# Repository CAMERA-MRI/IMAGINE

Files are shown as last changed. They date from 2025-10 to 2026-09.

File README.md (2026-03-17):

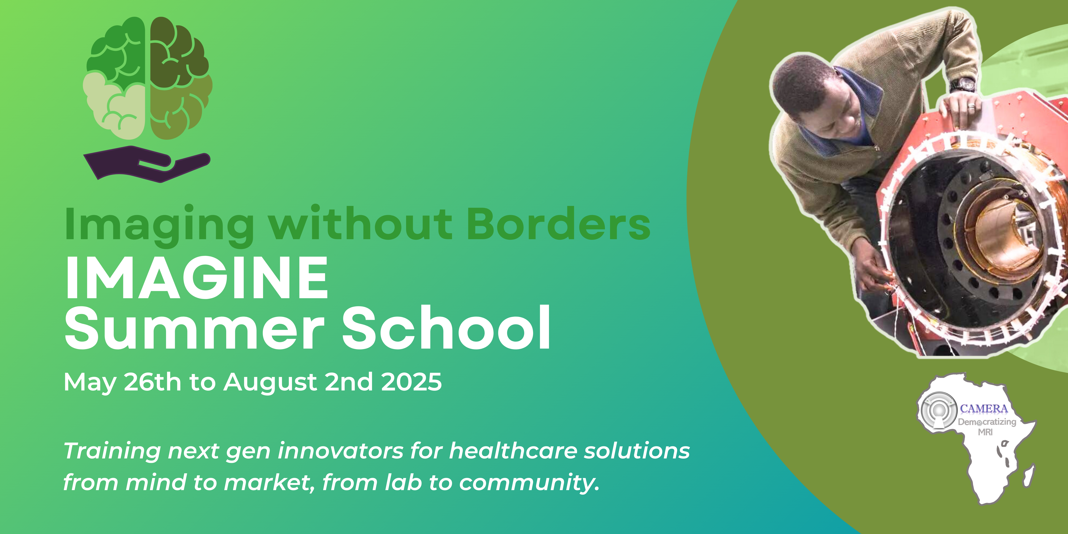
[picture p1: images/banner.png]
Banner.
<br/><br/>

# IMAGINE: Imaging Without Borders: Building a low-cost open-source low-field preclinical MR scanner. 

Imaging without Borders (IMAGINE) summer school is a hybrid training initiative of the Consortium for Advancement of MRI Education and Research in Africa (CAMERA). The summer school is designed to provide skills training to biomedical engineers and MR imaging personnel working in MRI hardware and scanner maintenance in Low- and Middle-income countries (LMICs) in Africa, Latin America, and Southeast Asia or clinicians and researchers interested in low-field and accessible imaging. IMAGINE implements RAD-AID’s Teach-Try-Use strategy, applied in CAMERA’s SPARK AI training program, to rapidly provide MR hardware and engineering competencies in resource-limited settings. In keeping with CAMERA’s training model, IMAGINE will use a combination of case-based and hands-on learning approaches to train a team of engineers, physicists, clinicians, and researchers who will work together as a network to grow their skills and collectively train others. IMAGINE is focused on training next-generation imaging innovators on how to use design thinking strategies and user-centered problem-solving skills to create low-cost open-source tools that will sustainably democratize diagnostic imaging and make it readily accessible to all. 

### Field Mapping Robot
Hardware and firmware developed for the IMAGINE field mapping robot are available here:  
➡️ [https://github.com/SipanHovsep/Field_mapper_robot](https://github.com/SipanHovsep/Field_mapper_robot)

### Halbach Design Genetic Algorithm
Code to the Magnet design Genetic Algorithm developed and used during IMAGINE can be accessed here: \
➡️ [https://github.com/tmachtelinckx/halbacharray-GA](https://github.com/tmachtelinckx/halbacharray-GA)

The files needed for the magnet configuration used for the scanner build in the IMAGINE Summer School are in the Halbach Array folder. These files are meant to be opened in Autodesk Inventor or Fusion360. There are also .stp files for the individual rings so you can see how it would print.

### RF Coil 
.stp files to print the RF Coil holder and description of all the necessary parameters are provided in the RF Coil folder.

### TR Switch
The switch used is the passive switch from the [Open Source Imaging Initiative](https://gitlab.com/osii/rf-system/tr-switches/passive-tr-switch). 

### The Control System used is MaRCoS controlled from the MARGE GUI
➡️ [MaRCoS MRI](https://github.com/marcos-mri) \
➡️ [MaRGE: A graphical environment for MaRCoS](https://github.com/josalggui/MaRGE)

## Citations
[1] Anazodo, Udunna C et al. “A framework for advancing sustainable magnetic resonance imaging access in Africa.” NMR in biomedicine vol. 36,3 (2023): e4846. doi:10.1002/nbm.4846 \
[2] Murali, Sanjana et al. “Bringing MRI to low- and middle-income countries: Directions, challenges and potential solutions.” NMR in biomedicine vol. 37,7 (2024): e4992. doi:10.1002/nbm.4992 \
[3] Negnevitsky, V., Vives-gilabert, Y., Algarín, J. M., Craven-Brightman, L., Pellicer-guridi, R., O'Reilly, T., Stockmann, J. P., Webb, A., Alonso, J., & Menküc, B. (2023). MaRCoS, an open-source electronic control system for low-field MRI. Journal of Magnetic Resonance, 350, 107424. https://doi.org/10.1016/j.jmr.2023.107424  \
[4] Algarín, J. M., Guallart-Naval, T., Borreguero, J., Galve, F., & Alonso, J. (2024). MaRGE: A graphical environment for MaRCoS. Journal of Magnetic Resonance, 361, 107662. https://doi.org/10.1016/j.jmr.2024.107662

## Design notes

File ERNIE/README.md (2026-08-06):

# 🧰 ERNIE 

 ## Overview

<p style="text-align: justify;">
The <b>CAMERA-IMAGINE-MRI Education (ERNIE) toolkit</b> was designed to facilitate immersive hands-on collaborative learning of open source (OS) low-field (LF) MRI engineering. ERNIE is a frugal educational toolkit for on-site construction of a 50 mT OS-LF ‘mice-like’ brain MRI scanner that can be readily reproduced in any setting using common assembly tools and without prior MRI engineering experience. The toolkit was designed as a reusable teaching resource consisting of:</p>

   1. A [30-minute lecture on OS-LF MR engineering concepts](https://github.com/CAMERA-MRI/IMAGINE/blob/main/ERNIE/Training%20sessions/Training%20material/Building%20your%20own%20Low%20field%20MRI_Dr%20Johnes_(%20MRI%20Uganda%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).

2. An [animation](https://github.com/CAMERA-MRI/IMAGINE/tree/main/ERNIE/Build%20your%20own%20Design/Magnet/Instructions/Animation) providing a step-by-step guide for scanner assembly, including the [magnet assembly guide](https://github.com/CAMERA-MRI/IMAGINE/blob/main/ERNIE/Build%20your%20own%20Design/Magnet/Instructions/How%20to%20Assemble%20the%20Magnet.pdf), [robot assembly guide and field mapping (quality assurance)](https://github.com/SipanHovsep/Field_mapper_robot).

3. A [bill of materials](https://github.com/CAMERA-MRI/IMAGINE/tree/main/ERNIE/Build%20your%20own%20Design) and [3D printing instructions for the magnet](https://github.com/CAMERA-MRI/IMAGINE/blob/main/ERNIE/Build%20your%20own%20Design/Magnet/Instructions/ERNIE%203D%20printing%20instructions.pdf) and robotic field mapping parts.

4. [Tools for onsite assembly](https://github.com/CAMERA-MRI/IMAGINE/tree/main/ERNIE/Build%20your%20own%20Design).

5. Instructions and software to build the magnet and map its field homogeneity.

6. The [magnet](https://github.com/CAMERA-MRI/IMAGINE/tree/main/ERNIE/Build%20your%20own%20Design/Magnet): a 7-ring, 80 mm (inner bore diameter) Halbach array producing ~50 mT, made from 98 neodymium (N48) magnets.
### ERNIE Toolkit  🧲 for Onsite Assembly and Magnetic Field Mapping with Portable Storage System
      
<p align="center">
toolkit
</p>
<p style="text-align: justify;">
 
### 💡 Objective
To provide a low-cost/open-source/hands-on educational toolkit for practical learning of Halbach-based MRI scanner assembly and field mapping. 
   
<p align="center"> 
   Objective 
</p>
   
### 🎯 Motivation
Practical experience in assembling low-field MRI scanners is rarely available to MRI researchers, which limits their understanding of MR physics and hardware design principles.   

<p align="center">
 New Motivation </p>
 
### ♻️ Reproducibility
<p style="text-align: justify;">
Two kits were designed as <b>ERNIE 1 & ERNIE 2 </b> as the <b>same kit </b> built at <b>2 different sites</b>. ERNIE 1 was first assembled at the 2025 ESMRMB pre-congress workshop and then re-assembled at the 2026 ISMRM conference in Cape Town, South Africa. ERNIE 2 on the other hand was first assembled at the Montreal Neurological Institute (MNI - The Neuro) and then re-assembled multiple times at the Montreal General Hospital, Polytechnique Montreal, The Douglas Health Hospital and 2026 ISMRM.
</p>
   
### ⭐ Impact
This toolkit was used to train participants at the ESMRMB 2025 Conference, The Montreal Neurological Institute, The Douglas, Polytech Montreal, Montreal General Hospital and ISMRM 2026 Conference. 

| **Metric** | **ESMRMB** | **Montreal Neurological Institute** | **Polytechnique Montréal** | **The Douglas** | **Montreal General Hospital** | **ISMRM** |
|:---|---:|---:|---:|---:|---:|---:|
| 🎓 **Training session** | ESMRMB | MNI | Polytechnique | Douglas | MGH | ISMRM |
| ⏱️ **Duration** | 7 h | 5 h | 3 h | 3 h | 3 h | 1.5 h |
| 👥 **Participants** | 59 | 26 | 13 | 20 | 18 | 86 |

 ### 🌍👥 Participants at different sites 

<p align="center">
   
   poly and neuro
</p>
<p align="center">
   ismrm git
   mgh and douglas pic for git
 </p>

   </p>
</p>

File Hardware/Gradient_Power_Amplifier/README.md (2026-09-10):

# Gradient Power Amplifier

The IMAGINE MRI scanner uses the open-source
[GPA-FHDO gradient power amplifier](https://github.com/menkueclab/GPA-FHDO)
to drive the X, Y, and Z gradient coils.

The GPA-FHDO is a four-channel gradient power amplifier designed for
low-field MRI applications. In the IMAGINE scanner, three channels are
used to drive the three gradient axes.

> **Note:** The GPA used in the IMAGINE scanner is based on the original
> GPA-FHDO design. Some components and implementation details were added
> or modified for our scanner configuration.

## Bill of Materials

The complete bill of materials (BOM) for the IMAGINE gradient power
amplifier is available here:

[Download the IMAGINE GPA BOM](./IMAGINE_GPA_BOM.xlsx)

The BOM includes the components used in our implementation, including
components that differ from or were added to the original GPA-FHDO design.

## Original GPA-FHDO Project

Original design and documentation:

https://github.com/menkueclab/GPA-FHDO

https://gpa-fhdo.readthedocs.io/en/latest/

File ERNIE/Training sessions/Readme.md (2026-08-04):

# 👥 Training Sessions
## Overview

<p style="text-align: justify;">
This section includes the educational sessions and training material related information.
Below are some of survey responses from the participants. We also includes a figure showing the robot and scanner setup during field mapping, field map results and a plot from one of the workshops (Montreal General Hospital Workshop). 
<p align= "center">

## 🧲Magnet, 🤖Robot setup and 📈 Magnetic Field Map Result.
 
<p align= "center">
  field map example
</p>

</p>

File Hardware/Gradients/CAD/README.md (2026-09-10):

# Gradient Coil CAD Files
This folder contains CAD and STL files for the X, Y, and Z gradient coil formers used in the low-field IMAGINE Halbach array MRI scanner.
STL files are provided for 3D printing.

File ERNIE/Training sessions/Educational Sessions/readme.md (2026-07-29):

# 🧑‍🏫 Educational Sessions
## Overview
<p style="text-align: justify;">
We conducted educational sessions to test the reproducibility of the ERNIE toolkit. This section includes educational apprach used and agendas used during the training sessions.

  <p align="center"> educational approach
</p>

## ESMRMB workshop Agenda
<p align="center"> esmrmb agenda</p>

## Montreal General Hospital (MGH) workshop Agenda 

<p align="center"> Mgh build session agenda 
</p>
</p>

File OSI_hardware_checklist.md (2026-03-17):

# OSI² CAB Review

## Review details

```
Project name: 
Project version: 
Project files: 

Review ID: 1.1/xx
Reviewer: 
Date: 
Approved: Yes / No
Total Points Hardware: XX / 17
```

---

## Note to Reviewers

- Please go through the checklist and provide detailed feedback that might be helpful to the project representative to justify a review score e.g. if you don't check a box, please explain what exactly is missing if appropriate.
- Each project is reviewed by at least 2 reviewers.
- If a project is being resubmitted, this is indicated with reference to the previous review report and the changes that have been made/points that were addressed.
- Mandatory requirements for projects to be published on [opensourceimaging.org](https://opensourceimaging.org/projects) are marked **in bold**.
- Open-source licenses for the project are checked beforehand by the `CAB Admin` or `CAB Editor`
- If a question is not applicable to the project, please check the box and write a short comment.
- If the hardware project contains software, please perform also the software review
- For questions and guidelines see also our CAB instructions [here](https://gitlab.com/osiiev/cab/-/blob/main/README.md).

---

## Scores for Hardware

### Readme

1. [x] **Is a README file (or equivalent) available with a project description?** (1)
2. [ ] Have the design considerations been explained? (1)

### Bill of Materials

1. [x] **Is a Bill of Materials (BoM) provided to reproduce the design?** (1)
2. [ ] Is the Bill of Materials complete/complies with our [best practices](https://gitlab.com/osiiev/cab/-/blob/main/guidelines/bill-of-materials.md)? (1)

### Source Files

1. [ ] **Are all files needed to reproduce the project according to the project description available in their native file format?** (1)

### Status of Freedom

1. [x] Are all source files editable with open-source software (e.g. FreeCAD, KiCAD)? (1)

### Production Files

1. [x] **Are all files needed to reproduce the project according to the project description available in a generally accessible export file format (e.g. STP, STL, GRB)?** (1)
2. [ ] Is the manufacturing environment (e.g. machine parameters) well defined or sufficiently explained to reproduce the production as intended? (1)
    > For instance, this is already given for a PCB, when complete Gerber files are provided. Then please grant this point.

### Assembly

1. [x] **Is the assembly of the project sufficiently explained, allowing for the complete replication of the project, e.g. by an assembly guide?** (1)
    > For some projects the assembly is clearly self-explanatory or not even needed, e.g. for one-piece 3D prints. Then please grant this point. 

### Development Tracking

1. [x] **Is a versioning scheme implemented (e.g. git repository)** (1)
2. [ ] Is an issue tracking implemented publicly? (1) 
3. [ ] Does the project have a communication space for questions, ideas, exchange with the developers or a user community? (1)

### Testing

1. [ ] Are testing routines available to evaluate the expected performance of the final design? (1)
2. [ ] Are testing routines complete (e.g. available for all subcomponents/subprocesses of the project build)? (1)

### Use

1. [ ] Is a user manual available? (1)
    > In case the intended use is clearly self-explanatory, so a manual is not needed. Then please grant this point.
2. [ ] Is a risk assessment or a safety notice available? (1)
3. [ ] Is information available (e.g. contact persons) if the project has been independently successfully replicated? (1)

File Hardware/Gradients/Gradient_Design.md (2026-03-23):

### How to build your own MRI Gradients
- CAD Design
- Gradient Optimization 
# How to build your own MRI Gradients
## CAD Design
The steps for the CAD design and 3D printing of the gradient coils using Autodesk AutoCAD

**Phase 1: Coordinate Import and Path Creation**

1. Data Preparation: Copy the x, y, and z coordinates into Excel and save them as a CSV file. Ensure that coordinates for each quadrant are saved separately.
2. Coordinate Import: Use the LINE command in AutoCAD to import the coordinates and visualize each quadrant.
3. Spiral Construction: Trim and connect the lines to form a spiral for each quadrant. Ensure the current direction in adjacent quadrants is opposite. Each quadrant must have two distinct ports: one for input and one for output.
4. Path Integration: Join the individual lines within each quadrant to create a single, continuous 3D POLYLINE.

**Phase 2: 3D Modeling and Sweeping**

5. Workspace Setup: Switch the AutoCAD workspace to 3D Modelling and change the viewport to a 3D View.
6. Profile Selection: Draw a circle with a diameter equal to the wire width. Center this circle on one of the ports of each quadrant.
7. Sweep Operation: Execute the SWEEP command. Select the circle as the object to sweep, press Enter, and then select the 3D polyline (the wire path) as the sweeping path.
8. Visual Verification: Change the workspace to multiple viewports (Top, Side, and Front). In the Front view, click the "Home" (house) icon and change the Visual Style to Realistic. (Alternatively, select Realistic directly from the View section).
9. Display Reset: Revert the workspace to a single viewport.
10. Workspace Transition: Return to the Drafting and Annotation view.

**Phase 3: Cylinder and Groove Construction**

11. Base Geometry: Draw a circle at the center (0, 0) with a radius equal to the outer radius of the gradient coil.
12. Shelling: Offset this circle inward by 3mm to create an inscribed circle.
13. Initial Extrusion: Extrude these circles to half the total height of the gradient coil (L/2) to create a half-cylinder.
14. Secondary Geometry: Draw a second set of circles (using the same offsets from steps 11 and 12) at the center (0, 0), positioned at either the top or bottom face of the first cylinder.
15. Full Extrusion: Extrude these circles in the opposite direction (positive or negative Z) to complete the other half of the coil height.
16. Merging Cylinder: Use the UNION command to merge the two half-cylinders into one solid, full-length cylinder for the gradient coil former.
17. Merging Coil Paths: Use the UNION command to merge all four coil quadrants into a single object.
18. Groove Creation: Use the SUBTRACT command to remove the quadrant coil objects from the cylinder, thereby creating the winding grooves.

**Phase 4: Prototyping and Testing**

19. Export: Generate an STL file for 3D printing using the STLOUT command.
20. Fabrication: 3D print the former and carefully wind the AWG (American Wire Gauge) wires into the manufactured grooves.
21. Simulation: Save the quadrant geometries independently and test the coil performance using CST Studio Suite or another electromagnetic simulation package.

## Gradient Optimization 
The optimization details for the gradient coils are available in this paper: 
Kassahun, H.B., Nayebare, M., Machtelinckx, T., Yazdanbakhsh, P., Obungoloch, J., Du Plessis, S. and Anazodo, U., 2025, July. Design and Optimization of Gradient Coils for Low-field Halbach Array Scanners Using the Discrete Wire Method. In 2025, the 47th Annual International Conference of the IEEE Engineering in Medicine and Biology Society (EMBC) (pp. 1-6). IEEE.

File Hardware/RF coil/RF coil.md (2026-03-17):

## RF Coil

| Parameter | Value |
|---|---|
| Number of Turns | 27 |
| Pitch between turns | 117/27= 4.333333 |
| Wire thickness | 1.65mm |
| Inductance | uH (Measured ) |
| Inner diameter | 58mm( After printing) and 60mm before printing  |
| Outer Diameter | 63mm |
| Length of turns | 117mm |
| Length of Coil | 143mm |
| Tuning Capacitance | 330pF+ 24pF+ 25pF( variable ) |
| Matching Capacitance | 47pF + 18pF |
| Center Frequency | 2.035MHz |
| Reflected Power | -30.7dB |
| Resistance on Smith Chat  | -52 ohms |

STEPS 
1. Place the RF coil in the MRI scanner and add gradients and a shield. 
2. Then connect the RF coil to the VNA to see the peak. 
3. Add capacitors on the tuning side ( S21). To attain a frequency of 2.1MHz for a 50 mT scanner system. 
4. After attaining the Tuning Capacitance, measure the quality factor of the coil, loaded and unloaded. 
5. The value of the Quality Factor should be greater than 1. In that case, add capacitors for the matching channel until the reflected power is closer to –50dB.

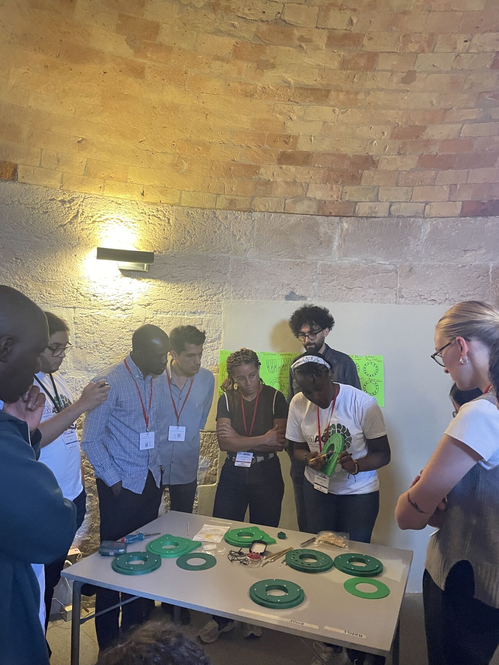
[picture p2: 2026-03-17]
images/Magnet team ESMRMB.jpeg

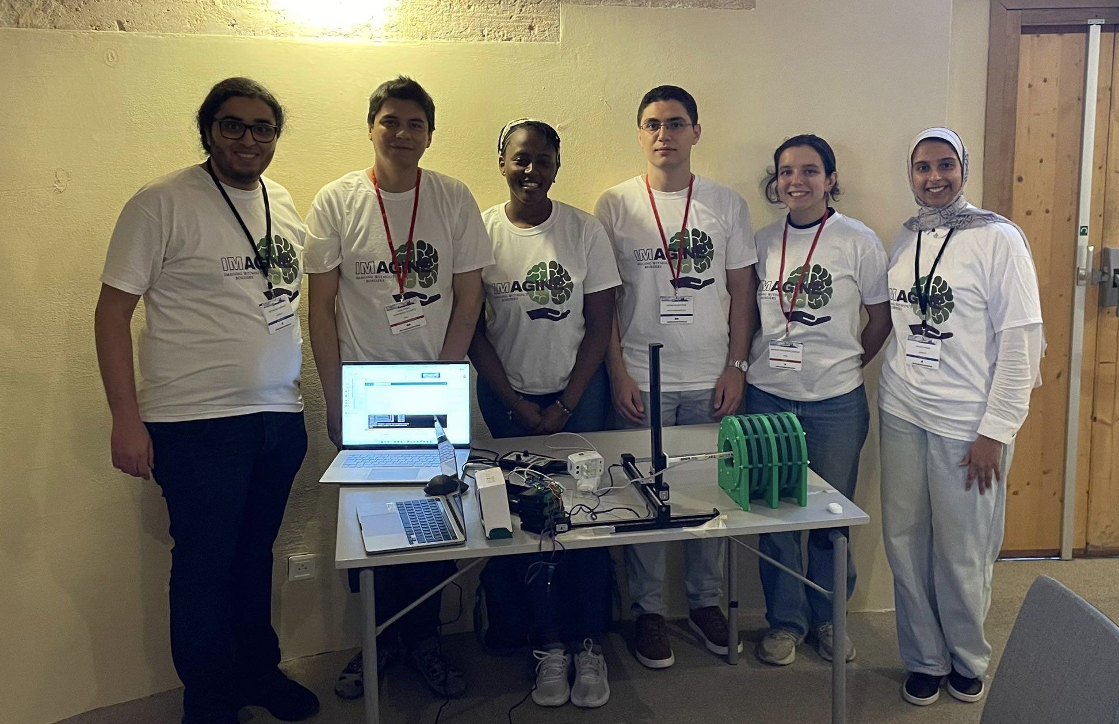
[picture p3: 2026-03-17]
images/Team leaders at ESMRMB.jpeg

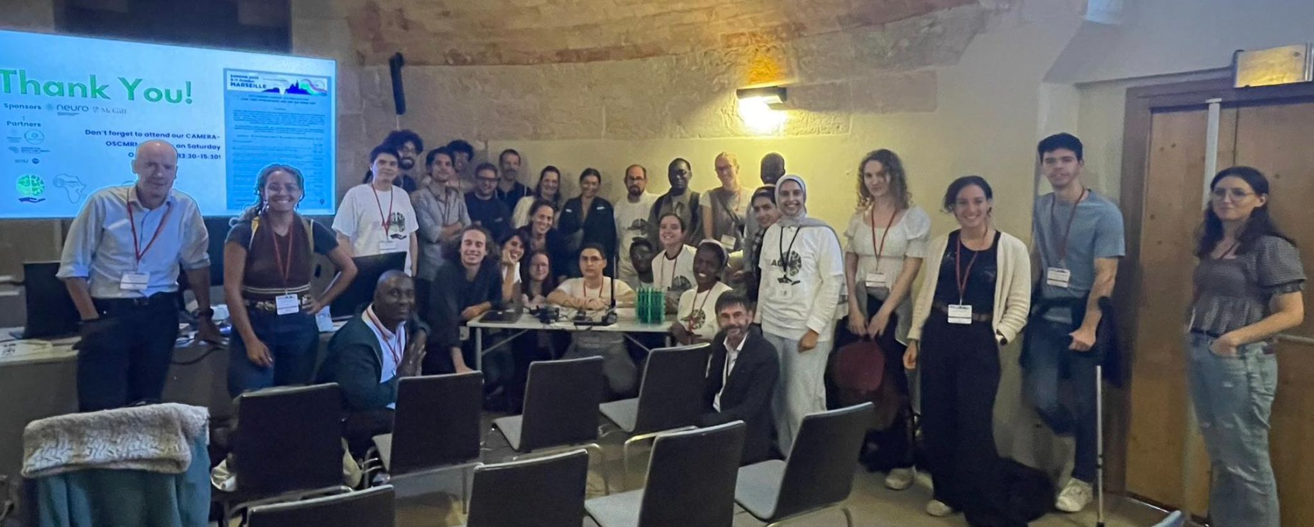
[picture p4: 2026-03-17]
images/Participants at ESMRMB Workshop.jpeg

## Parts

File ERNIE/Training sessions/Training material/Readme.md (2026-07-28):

# 🧠📚 Training Material

## Overview

<p style="text-align: justify;">

The following training materials were provided to participants before the workshop sessions to support their preparation and understanding of low-field MRI concepts and system construction:

- [Building Your Own Low-Field MRI – Dr. Johnes (MRI Uganda)](https://github.com/CAMERA-MRI/IMAGINE/blob/main/ERNIE/Training%20sessions/Training%20material/Building%20your%20own%20Low%20field%20MRI_Dr%20Johnes_(%20MRI%20Uganda%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)

- [Introduction Lecture on MRI – Guillermo](https://github.com/CAMERA-MRI/IMAGINE/blob/main/ERNIE/Training%20sessions/Training%20material/Introductory%20lecture%20on%20MRI_Guillermo.mp4)

- [List of Training Materials Including Existing Low-Field MRI Publications](https://github.com/CAMERA-MRI/IMAGINE/blob/main/ERNIE/Training%20sessions/Training%20material/List%20of%20training%20materials%2C%20Including%20existing%20low%20fiel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)

</p>

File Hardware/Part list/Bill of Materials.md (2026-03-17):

#                                                                                                                                                                                                                                                                                                                                                                                                                                                                                                                                                                                                                                                                                                                                                                                                                                                                                                                                                                                                                                                                                                                                                                                                                                                                                                                                                                                                                                                                                                                                                                                                                                                                                                                                                                                                                                                                                                                                                                                                                                                                                                                                                                                                                                                                                                                                                                                                                                                                                                                                                                                                                                                                                                                                                                                                                                                                                                                                                                                                                                                                                                                                                                                                                                                                                                                                                                                                                                                                                                                                                                                                                                                                                                                                                                                                                                                                                                                                                                                                                                                                                                                                                                                                                                                                                                                                                                                                                                                                                                                                                                                                                                                                                                                                                                                                                                                                                                                                                                                                                                                                                                                                                                                                                                                                                                                                                                                                                                                                                                                                                                                                                                                                                                                                                                                                                                                                                                                                                                                                                                                                                                                                                                                                                                                                                                                                                                                                                                                                                                                                                                                                                                                                                                                                                                                                                                                                                                                                                                                                                                                                                                                                                                                                                                                                                                                                                                                                                                                                                                                                                                                                                                                                                                                                                                                                                                                                                                                                                                                                                                                                                                                                                                                                                                                                                                                                                                                                                                                                                                                                                                                                                                                                                                                                                                                                                                                                                                                                                                                                                                                                                                                                                                                                                                                                                                                                                                                                                                                                                                                                                                                                                                                                                                                                                                                            Detailed Lab build schedule

| Item | Link | Price (before tax /shipping) |
| :---- | :---- | :---- |
| PCB for Red PItaya to GPA-FHDO adapter |  | Included in the budget |
| Red Pitaya |  |  |
| RFPA  |  |  |
| LNA |  |  |
| Internal shielding for RF: Copper sheet New Internal Shield  | [Amazon Copper sheet](https://www.amazon.ca/YuJingKey-Copper-0-05mm-Commercial-Projects/dp/B0DS2NQBJ5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) [Amazon](https://can01.safelinks.protection.outlook.com/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) | $21.99 $29.80 |
| External shielding: Aluminium sheet | [Amazon Aluminium sheet](https://www.amazon.ca/Bilaida-Stainless-Roll%EF%BC%8C0-2mm-Electronic-Equipment/dp/B0DKWH3DB7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) | $34.99x2 |
| Aluminum MaRCoS box |  [DigiKey](https://www.digikey.ca/en/products/detail/hammond-manufacturing/1590Z166/1090767) | $205.25 |
| Box for RFPA | [Amazon](https://www.digikey.ca/en/products/detail/bud-industries/CU-234/387028) | $19.26 |
| Connectors | [Amazon](https://www.amazon.ca/dp/B078K5563Y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) | $13.20 |
| SMA sockets | [Amazon](https://www.amazon.ca/BOOBRIE-Connector-Bulkhead-Extendable-Antennas/dp/B07WFLD2MX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) | $19.99 |
| SMA cables | [Amazon SMA Cables](https://www.amazon.ca/Superbat-Connector-Coaxial-Antenna-Analyzer/dp/B0BFPWJ3J9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) x2 | $15.99 x 2 |
| Ethernet port | [Amazon](https://www.amazon.ca/Ethernet-Extension-Shielded-Compatibility-Network/dp/B0D5QGCM3D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) x2 | $13.99 x 2 |
| nanoVNA | [Amazon nanoVNA](https://www.amazon.ca/Seesii-Analyzer-10KHz-1-5GHz-Measuring-Parameters/dp/B08132DJLS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) | $79.99 |
| Capacitors and  | Jack Electronics?? |  |
| Inductor | [https://www.digikey.ca/en/products/detail/codaca/CPER3231-101MC/16516449](https://www.digikey.ca/en/products/detail/codaca/CPER3231-101MC/16516449) | $62.42 |
| Grounding cables |  |  |
| BNC panel mount | [Amazon](https://www.amazon.ca/Connector-Bulkhead-Adapters-Coaxial-Adapter/dp/B09CG7WVHQ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) | $10.69 |
| BNC female to female | [Amazon](https://www.amazon.ca/Adapter-Connector-TUOLNK-Security-Extension/dp/B098J554XS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) | $10.99 |
| BNC male to male | [Amazon](https://www.amazon.ca/Adapter-Connector-TUOLNK-Security-Extension/dp/B098JH17L2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) | $12.99 |
| Sorting box | [Amazon](https://www.amazon.ca/dp/B003P0XRH0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) | $60.73 |
| Multimeter | [Digikey](https://www.digikey.ca/en/products/detail/fluke-electronics/FLUKE-15B/24398487) | $115.36 |
| Fastons | [Amazon](https://www.amazon.ca/dp/B08P6WQ4JS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) | $31.99 |
| Oscilloscope  | [Amazon](https://www.amazon.ca/Rigol-DHO804-Digital-Oscilloscope-Channels/dp/B0CGHQHQN7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) | $562.34 |
| Capacitors 10 uF \- 2mm | [DigiKey](https://www.digikey.ca/en/products/detail/samsung-electro-mechanics/CL21A106KAYNNNE/3888549) | $1.22 |
| Extension connector IDC female | [DigiKey](https://www.digikey.ca/en/products/detail/sullins-connector-solutions/SFH11-PBPC-D13-ST-BK/1990091) x 4 | $1.91x4 |
| Smitt Trigger | [DigiKey](https://www.digikey.ca/en/products/detail/texas-instruments/SN74LVC1G17DBVR/389051)x 10 | $1.06 |
| Fan | [DigiKey](https://www.digikey.ca/en/products/detail/nidec-components-corporation/F310R-05LC/1165517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) x 1 | $10.31 |
| Inductors |  |  |
| Ethernet RJ45 8p8c | [DigiKey](https://www.digikey.ca/en/products/detail/amphenol-cs-fci/54602-908LF/1001360) x2 | $1.03 x2 |
| Pin header male | [DigiKey](https://www.digikey.ca/en/products/detail/w%C3%BCrth-elektronik/61304011121/4846884) x3 | $2.01 x3 |
| Dual Row pin header male | [DigiKey](https://www.digikey.ca/en/products/detail/metz-connect-usa-inc/PR20203VBDN/12342894)x10 | $1.01 |
| Dual Row pin header female |  |  |
| Female pin header 2 pin | [DigiKey](https://www.digikey.ca/en/products/detail/w%C3%BCrth-elektronik/61300211821/21556337) x 10 | $4.41 for 10 |
| Female pin header 3 pin | [DigiKey](https://www.digikey.ca/en/products/detail/w%C3%BCrth-elektronik/61300311821/17737762) x10 | $3.03 for 10 |
| Female pin header 8 pin | [DigiKey](https://www.digikey.ca/en/products/detail/w%C3%BCrth-elektronik/61300811821/17737805) x 5 | $0.55 x5 |
| Female pin header 23 pin | [DigiKey](https://www.digikey.ca/en/products/detail/te-connectivity-amp-connectors/1-215307-3/2055846) x2  | $3.63 x2 |
| Sma jack | [DigiKey](https://www.digikey.ca/en/products/detail/amphenol-rf/132136/1011909) x 2 | $18.30 x 2 |
| Long SMA cables  | [DigiKey](https://www.digikey.ca/en/products/detail/te-connectivity-linx/CSE-SGAM-305-SGAM/14633985) x 8 | $12.18 x 8 |
| Short SMA cables | [DigiKey](https://www.digikey.ca/en/products/detail/te-connectivity-linx/CSE-SGAM-152-SGAM/14633984) x 2 | $17.92 x2 |
| SMA Female to BNC Male Adapter | [DigiKey](https://www.digikey.ca/en/products/detail/rf-solutions/ADP-SMAF-BNCM/4271257) x4 | $5.98x4 |
| SMA Adapters F-F | [DigiKey](https://www.digikey.ca/en/products/detail/gct/RFAD-SA3SA2-01-N-A/25819955) x 6 | $5.29 x6 |
| Inductor: 3.9 uH | [DigiKey](https://www.digikey.ca/en/products/detail/eaton-electronics-division/MCLA3216V1-3R9-R/13213363) x 10 got 2 | $1.34 |
| Capacitor 1.6 nF  Phase shifter | [DigiKey](https://www.digikey.ca/en/products/detail/kemet/C0805C162F5HACTU/7947875) x 10 | $2.24 |
| C inf \= 100 nF | [DigiKey](https://www.digikey.ca/en/products/detail/kemet/C1812C104KDRACAUTO/8109960) x 10 | $8.20 |
| 150uH Inductor for DC lines | [DigiKey](https://www.digikey.ca/en/products/detail/epcos-tdk-electronics/B78108S1154J000/652576) x 10 | $3.13 |
| I/O switch | [DigiKey](https://www.digikey.ca/en/products/detail/toshiba-semiconductor-and-storage/TLP170AM-V4TPL-E/12390883) x 3 | $1.94 x3 |
| Expensive Diode passive switch | [DigiKey](https://www.digikey.ca/en/products/detail/microchip-technology/UMX9989AP/13179363)  | $45.77 |
| Diodes passive switch | [DigiKey](https://www.digikey.ca/en/products/detail/infineon-technologies/BAT6804E6327HTSA1/1280953) x 3 | $0.42 x 3 |
| Arduino Mega  | [Amazon](https://www.amazon.ca/Arduino-A000067-ARDUINO-MEGA2560-REVISION/dp/B0046AMGW0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) x 1 | $74.72  |
| Power supply |  |  |
| T-connectors BNC | [DigiKey](https://www.digikey.ca/en/products/detail/te-connectivity-linx/ADP-BNCM-BNCF-T/17100339) X 5 | $4.33x5 $21.45 |
| BNC cables 60 cm | [DigiKey](https://www.digikey.ca/en/products/detail/pomona-electronics/5697-24/737382) x5 | $18.54 |
| BNC cables 15 cm | [DigiKey](https://www.digikey.ca/en/products/detail/amphenol-rf/115101-19-06-00/2505045) x6 | $16.93x6 |
| Panel SMA | [DigiKey](https://www.digikey.ca/en/products/detail/gct/RFAD-SA3SA2-01-N-A/25819955) x 4 | $5.29 x4 |
| SMA male to male | [DigiKey](https://www.digikey.ca/en/products/detail/te-connectivity-linx/ADP-SMAM-SMAM/1577234) x 4 | $7.72x4 |
| SMA panel solder | [DigiKey](https://www.digikey.ca/en/products/detail/molex/0732513152/3879154) x4 | $5.74x4 |
| Variable Capacitors | [DigiKey](https://www.digikey.ca/en/products/detail/ew-electronics/GKG60015/11689267) x 10 | $1.2 |
| Variable Capacitors | [DigiKey](https://www.digikey.ca/en/products/detail/passive-plus/PPZN30100/19235833) | $32.69 |
| Nuts and Bolts |  |  |
| Shielding box for LNA |  |  |
| Shielding Box for Tuning and Matching Circuit |  |  |
| Tape |  |  |
| Spanners |  |  |
| Power supply for the Robot | Amazon:minidodoca | $23x1 |
| Capacitor for gradients | Schaffner FN7563-63-M6  | 3x |
| Jamper wires for the Robot | Amazon | $23x1 |
| LNA Power Supply | [DigiKey](https://www.digikey.ca/en/products/detail/sra-soldering-products/KD3005D/10709902) | 129.47 |
| RFPA Power Supply | [DigiKey](https://www.digikey.ca/en/products/detail/sra-soldering-products/KD3005D/10709902) | 129.47 |
| BAT6804WH6327XTSA1 diodes | [Digikey](https://www.digikey.ca/en/products/detail/infineon-technologies/BAT6804WH6327XTSA1/2337549) X 20 | USD 7.14 |
| Inductors | [DigiKey](https://www.digikey.ca/en/products/detail/coilcraft/SER2014-402MLD/21381062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) X 4 | Usd 42.55 |
| 820pF capacitors: 4 |  [Digikey](https://www.digikey.ca/en/products/detail/kemet/C2220C821JZGACTU/1086644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) x 6 |  USD 42.54 |
| SMA PCB THT Jack Right Angle WR-SMA | [DigiKey](https://www.digikey.ca/en/products/detail/w%C3%BCrth-elektronik/60311002114501/10106987) x 3 | Usd 28.8 |
| Aluminum Box for switch |  [Amazon](https://www.digikey.ca/en/products/detail/bud-industries/CU-234/387028) | $19.86 |
| Aluminium box for RFPA | [Amazon](https://www.digikey.ca/en/products/detail/bud-industries/CU-234/387028) | $19.86 |
| **Circuit diagram**  | Reference: [Gitlab](https://gitlab.com/osii/rf-system/tr-switches/passive-tr-switch/-/blob/main/src/pcb-tr-switch/BOM.csv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) | ![][image1] |

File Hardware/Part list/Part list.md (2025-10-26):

## Here are some of the tools and equipment you are going to need if you want to replicate the IMAGINE Scanner

| Item | Link | Price (before tax / shipping) |
|---|---|---|
| PCB for Red Pitaya to GPA-FHDO adapter | -- | – |
| Internal shielding for RF: Copper sheet | [Amazon Copper sheet](https://can01.safelinks.protection.outlook.com/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) | $29.80 |
| External shielding: Aluminium sheet | [Amazon Aluminium sheet](https://www.amazon.ca/Bilaida-Stainless-Roll%EF%BC%8C0-2mm-Electronic-Equipment/dp/B0DKWH3DB7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) | $34.99 × 2 |
| Aluminum MaRCoS box | [DigiKey](https://www.digikey.com) | $205.25 |
| Box for RFPA | [Amazon](https://www.amazon.com) | $19.26 |
| Connectors | [Amazon](https://www.amazon.com) | $13.20 |
| SMA sockets | [Amazon](https://www.amazon.com) | $19.99 |
| SMA cables | [Amazon SMA Cables](https://www.amazon.com) | $15.99 × 2 |
| Ethernet port | [Amazon](https://www.amazon.com) | $13.99 × 2 |
| nanoVNA | [Amazon nanoVNA](https://www.amazon.com) | $79.99 |
| Inductor | [DigiKey](https://www.digikey.ca/en/products/detail/codaca/CPER3231-101MC/16516449) | $62.42 |
| BNC panel mount | [Amazon](https://www.amazon.com) | $10.69 |
| BNC female to female | [Amazon](https://www.amazon.com) | $10.99 |
| BNC male to male | [Amazon](https://www.amazon.com) | $12.99 |
| Sorting box | [Amazon](https://www.amazon.com) | $60.73 |
| Multimeter | [DigiKey](https://www.digikey.com) | $115.36 |
| Fastons | [Amazon](https://www.amazon.com) | $31.99 |
| Oscilloscope | [Amazon](https://www.amazon.com) | $562.34 |
| Capacitors 10 µF – 2mm | [DigiKey](https://www.digikey.com) | $1.22 |
| Extension connector IDC female | [DigiKey](https://www.digikey.com) | $1.91 × 4 |
| Schmitt Trigger | [DigiKey](https://www.digikey.com) | $1.06 × 10 |
| Fan | [DigiKey](https://www.digikey.com) | $10.31 |
| Ethernet RJ45 8p8c | [DigiKey](https://www.digikey.com) | $1.03 × 2 |
| Pin header male | [DigiKey](https://www.digikey.com) | $2.01 × 3 |
| Dual Row pin header male | [DigiKey](https://www.digikey.com) | $1.01 × 10 |
| Female pin header 2 pin | [DigiKey](https://www.digikey.com) | $4.41 (10 pcs) |
| Female pin header 3 pin | [DigiKey](https://www.digikey.com) | $3.03 (10 pcs) |
| Female pin header 8 pin | [DigiKey](https://www.digikey.com) | $0.55 × 5 |
| Female pin header 23 pin | [DigiKey](https://www.digikey.com) | $3.63 × 2 |
| SMA jack | [DigiKey](https://www.digikey.com) | $18.30 × 2 |
| Long SMA cables | [DigiKey](https://www.digikey.com) | $12.18 × 8 |
| Short SMA cables | [DigiKey](https://www.digikey.com) | $17.92 × 2 |
| SMA Female to BNC Male Adapter | [DigiKey](https://www.digikey.com) | $5.98 × 4 |
| SMA Adapters F-F | [DigiKey](https://www.digikey.com) | $5.29 × 6 |
| Inductor: 3.9 µH | [DigiKey](https://www.digikey.com) | $1.34 |
| Capacitor 1.6 nF (Phase shifter) | [DigiKey](https://www.digikey.com) | $2.24 |
| C inf = 100 nF | [DigiKey](https://www.digikey.com) | $8.20 |
| 150 µH Inductor for DC lines | [DigiKey](https://www.digikey.com) | $3.13 |
| I/O switch | [DigiKey](https://www.digikey.com) | $1.94 × 3 |
| Expensive Diode passive switch | [DigiKey](https://www.digikey.com) | $45.77 |
| Diodes passive switch | [DigiKey](https://www.digikey.com) | $0.42 × 3 |
| Arduino Mega | [Amazon](https://www.amazon.com) | $74.72 |
| T-connectors BNC | [DigiKey](https://www.digikey.com) | $4.33 × 5 |
| BNC cables 60 cm | [DigiKey](https://www.digikey.com) | $18.54 |
| BNC cables 15 cm | [DigiKey](https://www.digikey.com) | $16.93 × 6 |
| Panel SMA | [DigiKey](https://www.digikey.com) | $5.29 × 4 |
| SMA male to male | [DigiKey](https://www.digikey.com) | $7.72 × 4 |
| SMA panel solder | [DigiKey](https://www.digikey.com) | $5.74 × 4 |
| Variable Capacitors 10–60 pF | [DigiKey](https://www.digikey.com) | $1.20 |
| Variable Capacitors 18–300 pF | [DigiKey](https://www.digikey.com) | $32.69 |
| Power supply for the Robot | [Amazon](https://www.amazon.com) | $23 |
| Jamper wires for the Robot | [Amazon](https://www.amazon.com) | $23 |
| LNA Power Supply | [DigiKey](https://www.digikey.com) | $129.47 |
| RFPA Power Supply | [DigiKey](https://www.digikey.com) | $129.47 |

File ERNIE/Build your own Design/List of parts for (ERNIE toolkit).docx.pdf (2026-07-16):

ERNIE Toolkit Build of Materials and Parts Checklist
Carrying Case
No. | Part | Part Num ber | Notes | Quan tity | Total Cost( Canadian dollars) | 3D Printed (Yes/No) | On-site for Assembly ✔ (Yes/No)
1. | Case (https://www.amazon.ca/Atlantic-Acclaim-Hardside-Spinner-20-Inch/dp/B09LZNQLB9) | AL2 1769 009 | The Nanuk 935 hard case (https://www.amazon.ca/Nanuk-Waterproof-Hard-Wheels-Empty/dp/B00BP8UL9Q) can also be used | 1 | $90.55 | No

Subtotal: $90.55
Magnet
No. | Part | Part Number | Notes | Quantity | Total Cost (Canadian dollars) | 3D Printed (Yes/N o) | Added to Assembly ✔/ Not yet added to the Assembly | Disassem bled ✔/ Not yet Disassem bled
1. Ring | 42 (with PLA)* (https://ca.store.bambulab.com/products/pla-basic-filament?variant=541209412732915753) | | Approxim ately(Appr .) 134g of PLA per ring | 2 | - | Yes
2. Ring | 251(wi th PLA)* (https://ca.store.bambulab.com/products/pla-basic-filament?variant=541209412732915753) | | Appr. 134g of PLA per ring | 2 | - | Yes
3. Ring | 288 | | Appr. 134g of | 2 | - | Yes

No. | Part | Part Number | Notes | Quantity | Total Cost (Canadian dollars) | 3D Printed (Yes/N o) | Added to Assembly ✔/ Not yet added to the Assembly | Disassem bled ✔/ Not yet Disassem bled
| (with PLA)* (https://ca.store.bambulab.com/products/pla-basic-filament?variant=541209412732915753) | | PLA per ring
4. Ring | 321 (with PLA)* (https://ca.store.bambulab.com/products/pla-basic-filament?variant=541209412732915753) | | Appr. 134g of PLA per ring | 1 | - | Yes
5. Lids | for Rings 42 (with PLA)* (https://ca.store.bambulab.com/products/pla-basic-filament?variant=541209412732915753) | | Apr. 45g required to print each lid | 2 | - | Yes
6. Lids | for Rings 251 | | Apr. 45g required to print each lid | 2 | - | Yes
7. Lids | for Rings 288 (with PLA)* (https://ca.store.bambulab.com/products/pla-basic-filament?variant=541209412732915753) | | Apr. 45g required to print each lid | 2 | - | Yes
8. Lids | for | | Apr. 45g required to | 1 | - | Yes

No. | Part | Part Number | Notes | Quantity | Total Cost (Canadian dollars) | 3D Printed (Yes/N o) | Added to Assembly ✔/ Not yet added to the Assembly | Disassem bled ✔/ Not yet Disassem bled
| Ring 321 (with PLA)* (https://ca.store.bambulab.com/products/pla-basic-filament?variant=541209412732915753) | | print each lid
9. 180mm | Brass Rods (https://www.mcmaster.com/catalog/131/3633/90162A050) | 90162A05 0 | Two 1m brass rods can be bought. 1 brass rod = five 160mm rods | 8(166mm each) | $39.54 | No
10. Ring | Spacer s (3D printed ) | | Appr. 100g of PLA is required to print 80 ring spacers | 48 | - | Yes
11. M4 | Brass Nuts (https://www.amazon.ca/100pcs-Solid-Brass-Copper-Screw/dp/B0CQGYC7JZ?s=industrial) | B0CQGY C7JZ | 50 pieces | 8 | $11.33 | No
12. M3 | Nylon / | a23122400 ux0074 | Brass screws are preferred- | 54 | $13.99 | No

No. | Part | Part Number | Notes | Quantity | Total Cost (Canadian dollars) | 3D Printed (Yes/N o) | Added to Assembly ✔/ Not yet added to the Assembly | Disassem bled ✔/ Not yet Disassem bled
| Brass (https://www.amazon.ca/dp/B0CT3W8148?ref_=cm_sw_r_cp_ud_ct_V3A7QBZ2PN0M0N5663C1&th=1) Screws | | 60 pieces per packet
13. Dome- | Shaped Nuts (https://www.mcmaster.com/products/dome-nuts/thread-size~m4/) | 90527A50 5 | 100 pieces per packet | 8 | $22.96 | No
14. Washer | s (https://www.mcmaster.com/catalog/131/3696/95610A150) | 95610A15 0 | 100 pieces per packet | 16 | $7.70 | No
15. Neody | mium Magnet s (https://www.magfine.ca/products/neodymium-magnet-square-13mm-x-12mm-x-5mm) (12mm X12m mX12 mm) | | Specify dimension s to the vendor. $5.87 per magnet | 98 | $575.26 | No
16. Refere | nce Neody mium Magnet s | | These are made from the set of Neodymiu m magnets purchased | 4 | $23.48 | No
17. M3 | Brass Heat (https://www.amazon.ca/dp/B0DC43HJKN) | a24062300 ux0395 | 100 pieces per packet | 54 | $17.69 | No

No. | Part | Part Number | Notes | Quantity | Total Cost (Canadian dollars) | 3D Printed (Yes/N o) | Added to Assembly ✔/ Not yet added to the Assembly | Disassem bled ✔/ Not yet Disassem bled
| Set inserts (https://www.amazon.ca/dp/B0DC43HJKN)
18. PLA, (https://ca.store.bambulab.com/products/pla-basic-filament?variant=541209412732915753) | PETG, ABS | | Different colors depending on choice. | 4 | $25.99 | No

Subtotal: $737.94

No. | Part | Notes | Quanti ty | Total Cost( Canadian dollars) | 3D Printed (Yes/No) | On-site for Assembly ✔ (Yes/No)
1. Neodymi | um magnets | These are necessary to replace broken magnets (https://www.magfine.ca/products/neodymium-magnet-square-13mm-x-12mm-x-5mm) | 10 | $58.7 | No

Subtotal: $58.7

Tools needed for Magnet Assembly
No. | Tool | Part number
Notes | Quan
tity

Total
cost

Availabl
e
(Yes/No)

Onsite for
Assembly
✔/

Returned to
box ✔/

| | | | | | | Not onsite for Assembly | Not returned to Box
1. Screw | Drivers (https://www.amazon.ca/13-Pieces-Screwdrivers-Screwdriver-Magnetizer-demagnetizer/dp/B0CXSYBCXW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) Screw Drivers (https://www.amazon.ca/Screwdriver-Adjustable-Multitool-Security-Phillips/dp/B09XV7P17T) | 06973932 450615 | Select a crosshead / philips shaped with a tight grip | 2 2 | $20.99 $33.98 | No
2. | Spanners (https://www.amazon.ca/gp/product/B0DXPGQL98/ref=ox_sc_act_title_1?smid=A1H7SZ6E7GRTDF&th=1) | hta25010 6hh00121 5 | 7mm Open Wrench | 2 | $25.59 | No
3. | Compass (https://www.amazon.ca/Suunto-SS012277013-MCB-Black-Compass/dp/B002FA9GYE?mcid=dc042d5ffd67304f88e9c80f93f036de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) | | | 2 | $54.99 | No
4. Permanen | t Markers (https://www.amazon.ca/Sharpie-Permanent-4-Carded-Assorted-35113PP/dp/B000GOZXA2?s=office) | SAN3511 3PP | | 4 | $13.78 | No
5. Vernier | Caliper (https://www.amazon.ca/Kynup-Measuring-Stainless-Waterproof-Protection/dp/B07X8JQ8L5) | USQC033 01915 | 6 inch | 1 | $34.99 | No
6. | Ruler (https://www.amazon.ca/Transparent-Measuring-Suitable-Childrens-Centimeter/dp/B09B6V3PGM) | 4 | Must be non-magneti c | 1 | $6.69 | No

Subtotal: $191.01

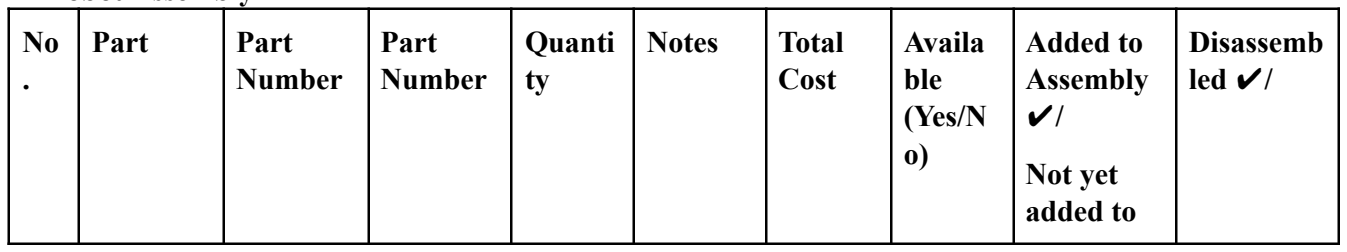
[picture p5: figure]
Part; Number; Part Number; Quanti ty; Notes; Total; Cost; Availa ble (Yes/N o); Added to Assembly ✔/; Not yet added to; Disassemb led ✔/

Robot Assembly

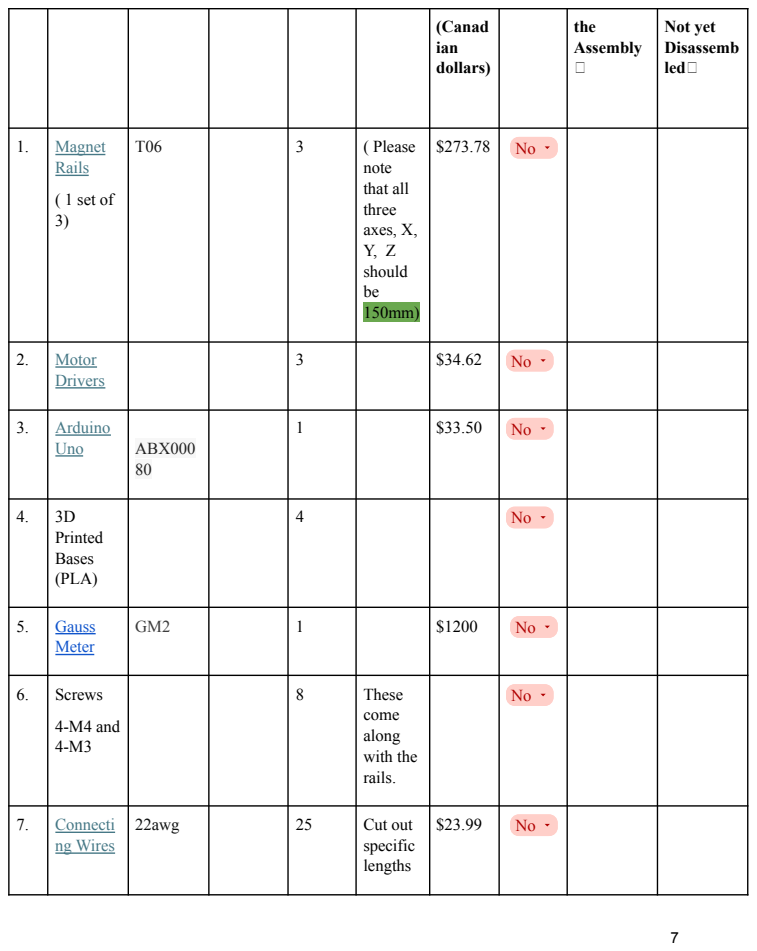
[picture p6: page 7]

(Canad ian dollars) | | the Assembly  | Not yet Disassemb led

1. Magnet | Rails (https://www.aliexpress.com/item/1005005534966065.html) ( 1 set of 3) | T06 | 3 | ( Please note that all three axes, X, Y, Z should be 150mm) | $273.78 | No

2. Motor | Drivers (https://www.aliexpress.com/item/1005005967708477.html) | | 3 | | $34.62 | No

3. Arduino | Uno (https://thepihut.com/products/arduino-uno-r4-minima) | ABX000 80 | 1 | | $33.50 | No

4. 3D | Printed Bases (PLA) | | 4 | | | No

5. Gauss | Meter (https://www.alphalabinc.com/products/gm2/) | GM2 | 1 | | $1200 | No

6. Screws | 4-M4 and 4-M3 | | 8 | These come along with the rails. | | No

7. Connecti | ng Wires (https://www.amazon.ca/TUOFENG-Hookup-Wires-6-Different-Colored/dp/B0CM2Y7V1Z) | 22awg | 25 | Cut out specific lengths | $23.99 | No

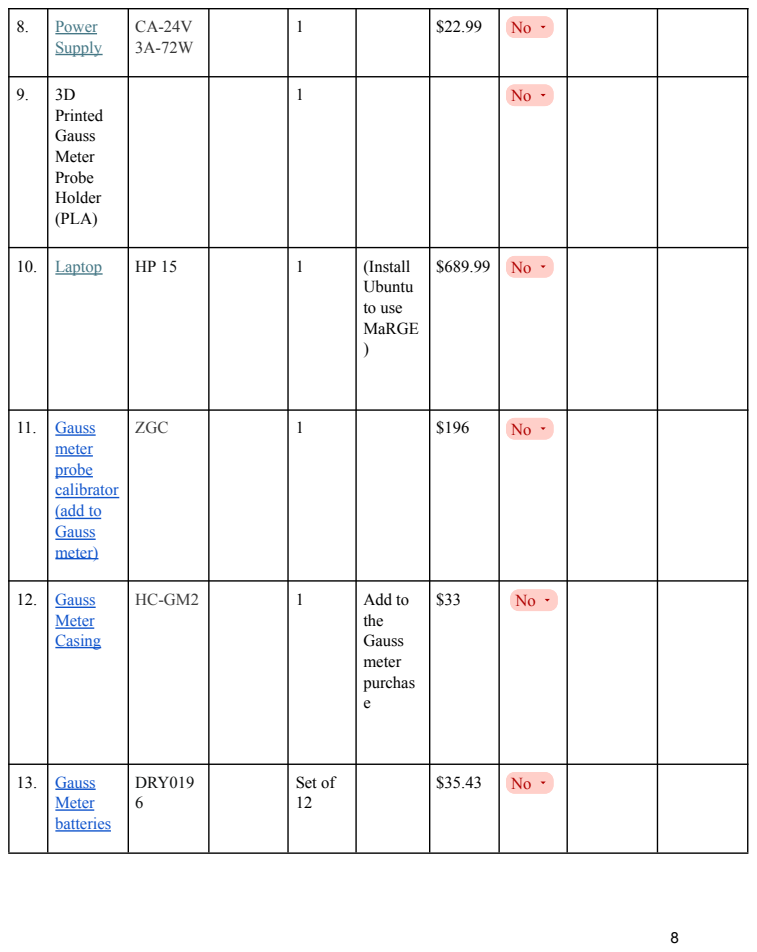
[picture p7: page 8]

8. Power | Supply (https://www.amazon.ca/dp/B0B9XGQQSR?s=industrial&sp_csd=d2lkZ2V0TmFtZT1zcF9kZXRhaWw) | CA-24V 3A-72W | 1 | | $22.99 | No

9. 3D | Printed Gauss Meter Probe Holder (PLA) | | 1 | | | No

10. | Laptop (https://www.amazon.ca/dp/B0GMV73BNZ?ref_=pe_153780070_1227138250&th=1) | HP 15 | 1 | (Install Ubuntu to use MaRGE ) | $689.99 | No

11. Gauss | meter probe calibrator (add to Gauss meter) (https://www.alphalabinc.com/products/zgc/) | ZGC | 1 | | $196 | No

12. Gauss | Meter Casing (https://www.alphalabinc.com/products/hc-gm2/) | HC-GM2 | 1 | Add to the Gauss meter purchas e | $33 | No

13. Gauss | Meter batteries (https://www.amazon.ca/Interstate-Batteries-DRY0196-9v-battery_single-use/dp/B00LZ5NCC2?th=1) | DRY019 6 | Set of 12 | | $35.43 | No

3D
printed
Motor
driver
casing
(PLA)

No

Subtotal: $2543.3

Tools needed for Robot Assembly
No. | Tool | Notes | Quantity | Total Cost | Available (Yes/No) | Returned to box ✔/ Not returned to the box
1. | Screw Drivers (https://www.amazon.ca/13-Pieces-Screwdrivers-Screwdriver-Magnetizer-demagnetizer/dp/B0CXSYBCXW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) | One can buy a set of screw drivers; however, flat head screw drivers are preferred. ) | 2 | N/A* | No
2. | Allen Keys (https://www.amazon.ca/Metric-Extension-Impact-Driver-Repair/dp/B0F2HB6K22) | Hex Bit Set | 4 | $25.98 | No
3. | Masking Tape (https://www.amazon.ca/AmazonBasics-Masking-Tape-Inch-Rolls/dp/B07QHSKGMH) | AB506-3 | 1 | $9.05 | No

Subtotal: $56.02
*Previously captured

Magnet Disassembly
No . | Part | Part Number | Quantity | Notes | Total cost | Available | On-site for Assembly ✔ (Yes/NO)
1. | Magnet Ouster (https://www.amazon.ca/Heiwa-Wooden-Chospticks-Pairs-Pack/dp/B07B6LP24M) | 871392000899 | 1 | Sharpen them to push out | $11.54 | No

| | | | magnets from rings easily
2. 3D Printed | Disassembly Tray (PLA) | | 1 | | | No
3. 3D Printed | Disassembly Tray Cover (PLA) | | 1 | | | No
4. Cutter (to | sharpen the Ousters) (https://www.amazon.ca/TIFICAL-Retractable-Snap-Off-Wrapping-Cardboard/dp/B0D634MZ99) | 0163925152 44 | 1 | | $8.99 | No
5. Brass Heat set | inserts (https://www.amazon.ca/dp/B0DC43HJKN) | a24062300ux0 395 | 9 | M3-same as the heat set inserts used in the rings | | No
6. Brass Screws- | non magnetic | | 9 | Same as brass screws used with rings | | No

Subtotal: $20.53

Electronics required for signal generation

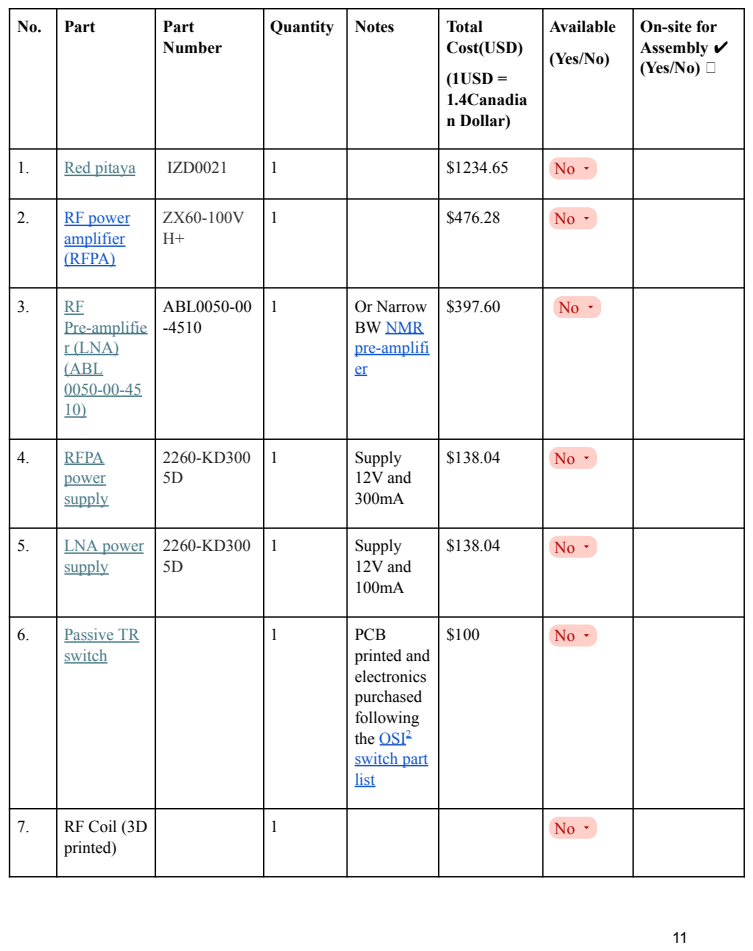
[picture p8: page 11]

No. | Part | Part Number | Quantity | Notes | Total Cost(USD) (1USD = 1.4Canadia n Dollar) | Available (Yes/No) | On-site for Assembly ✔ (Yes/No) 

1. | Red pitaya (https://redpitaya.com/product/sdrlab-122-16-standard-kit/?cat=c102) | IZD0021 | 1 | | $1234.65 | No

2. RF power | amplifier (RFPA) (https://www.mouser.ca/ProductDetail/Mini-Circuits/ZX60-100VH+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) | ZX60-100V H+ | 1 | | $476.28 | No

3. RF | Pre-amplifie r (LNA) (ABL 0050-00-45 10) (https://drive.google.com/file/d/1gmChqRjbeQmWzP2a9IR3v9yzpgMjObmQ/view) | ABL0050-00 -4510 | 1 | Or Narrow BW NMR pre-amplifi er (https://elcry.com/vz/elcry1-lf.pdf) | $397.60 | No

4. RFPA | power supply (https://www.digikey.ca/en/products/detail/sra-soldering-products/KD3005D/10709902) | 2260-KD300 5D | 1 | Supply 12V and 300mA | $138.04 | No

5. LNA power | supply (https://www.digikey.ca/en/products/detail/sra-soldering-products/KD3005D/10709902) | 2260-KD300 5D | 1 | Supply 12V and 100mA | $138.04 | No

6. Passive TR | switch (https://gitlab.com/osii/rf-system/tr-switches/passive-tr-switch) | | 1 | PCB printed and electronics purchased following the OSI² switch part list (https://gitlab.com/osii/rf-system/tr-switches/passive-tr-switch/-/blob/main/src/pcb-tr-switch/BOM.csv) | $100 | No

7. RF Coil (3D | printed) | | 1 | | | No

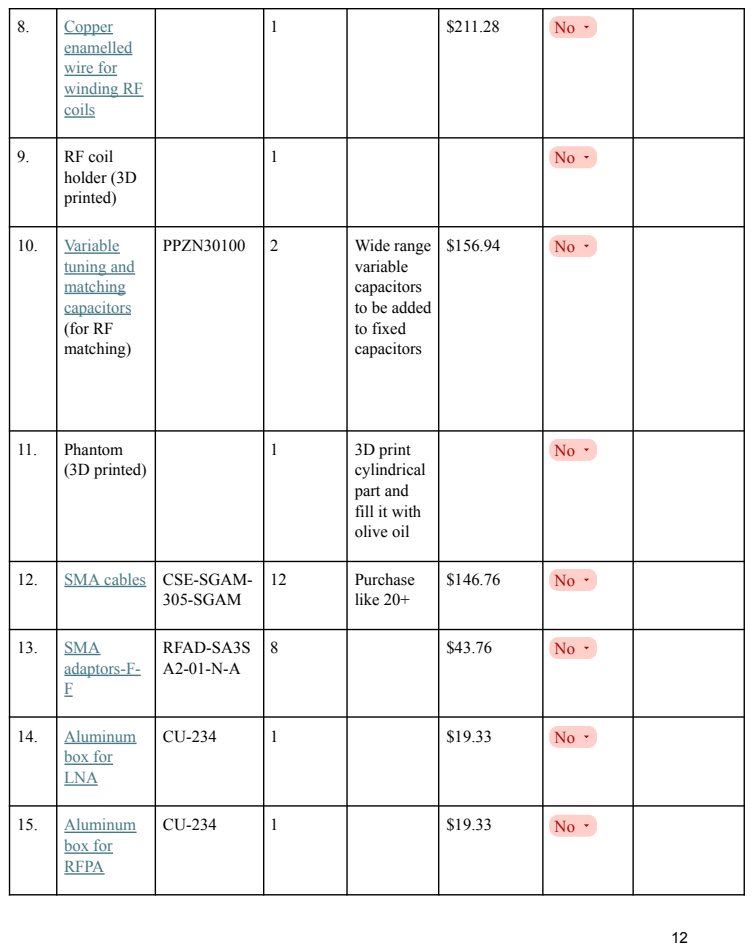
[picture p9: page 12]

8. Copper | enamelled wire for winding RF coils (https://www.digikey.ca/en/products/detail/cnc-tech/610216/4924215) | | 1 | | $211.28 | No

9. RF coil | holder (3D printed) | | 1 | | | No

10. Variable | tuning and matching capacitors (https://www.digikey.ca/en/products/detail/passive-plus/PPZN30100/19235833) (for RF matching) | PPZN30100 | 2 | Wide range variable capacitors to be added to fixed capacitors | $156.94 | No

11. Phantom | (3D printed) | | 1 | 3D print cylindrical part and fill it with olive oil | | No

12. | SMA cables (https://www.digikey.ca/en/products/detail/te-connectivity-linx/CSE-SGAM-305-SGAM/14633985) | CSE-SGAM-305-SGAM | 12 | Purchase like 20+ | $146.76 | No

13. SMA | adaptors-F-F (https://www.digikey.ca/en/products/detail/gct/RFAD-SA3SA2-01-N-A/25819955) | RFAD-SA3S A2-01-N-A | 8 | | $43.76 | No

14. Aluminum | box for LNA (https://www.digikey.ca/en/products/detail/bud-industries/CU-234/387028) | CU-234 | 1 | | $19.33 | No

15. Aluminum | box for RFPA (https://www.digikey.ca/en/products/detail/bud-industries/CU-234/387028) | CU-234 | 1 | | $19.33 | No

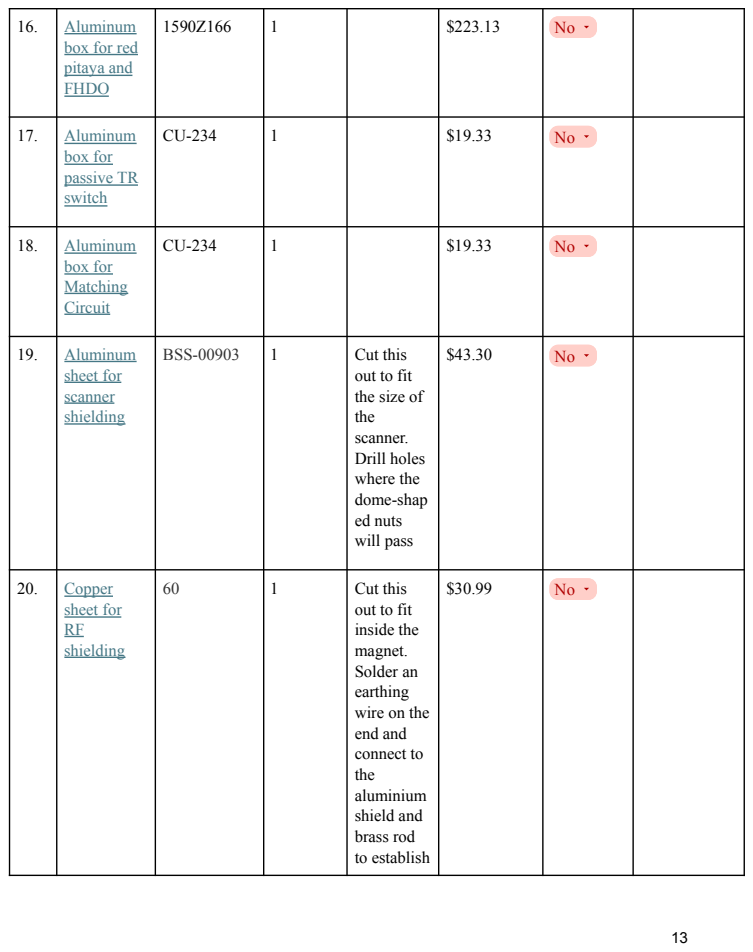
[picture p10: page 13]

16. Aluminum | box for red pitay (https://www.digikey.ca/en/products/detail/hammond-manufacturing/1590Z166/1090767) a and FHDO | 1590Z166 | 1 | | $223.13 | No

17. Aluminum | box for passive TR switch (https://www.digikey.ca/en/products/detail/bud-industries/CU-234/387028) | CU-234 | 1 | | $19.33 | No

18. Aluminum | box for Matching Circuit (https://www.digikey.ca/en/products/detail/bud-industries/CU-234/387028) | CU-234 | 1 | | $19.33 | No

19. Aluminum | sheet for scanner shielding (https://www.amazon.ca/Bilaida-Stainless-Roll%EF%BC%8C0-2mm-Electronic-Equipment/dp/B0DKWH3DB7) | BSS-00903 | 1 | Cut this out to fit the size of the scanner. Drill holes where the dome-shap ed nuts will pass | $43.30 | No

20. Copper | sheet for RF shielding (https://www.amazon.ca/dp/B0CDGQ95YB) | 60 | 1 | Cut this out to fit inside the magnet. Solder an earthing wire on the end and connect to the aluminium shield and brass rod to establish | $30.99 | No

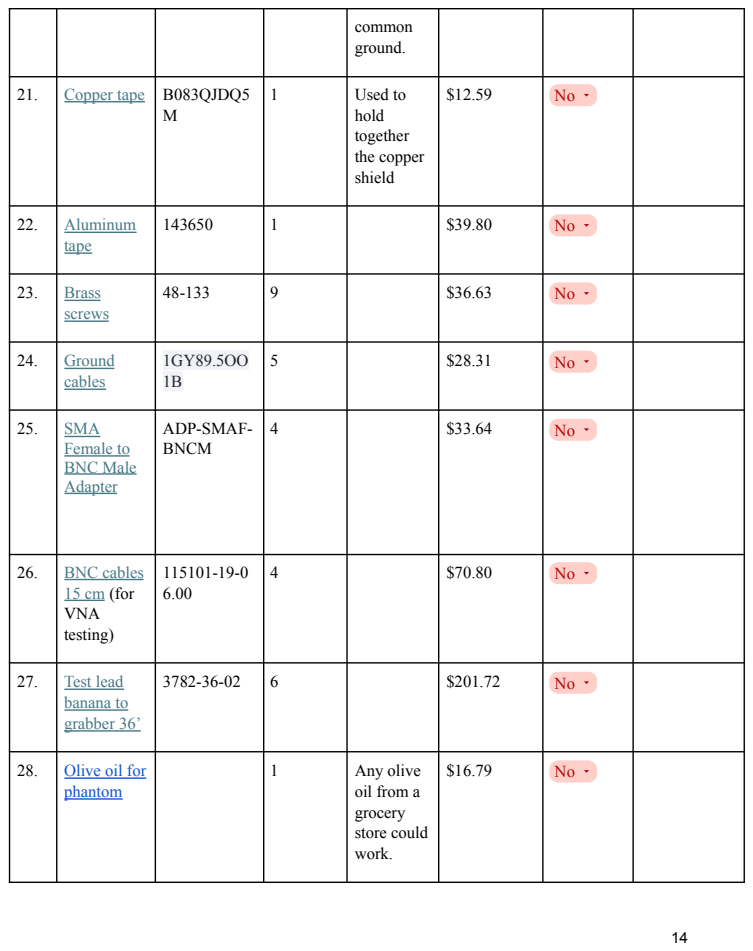
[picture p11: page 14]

common ground.

21. | Copper tape (https://www.amazon.ca/Single-Sided-Conductive-Shielding-Repellent-Electrical/dp/B083QJDQ5M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) | B083QJDQ5 M | 1 | Used to hold together the copper shield | $12.59 | No

22. Aluminum | tape (https://canada.newark.com/3m/1436-50mm/tape-aluminium-foil-50mmx50m/dp/52R8749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) | 143650 | 1 | | $39.80 | No

23. Brass | screws (https://www.digikey.ca/en/products/detail/knowles-voltronics/48-133/18680028?gclsrc=aw.ds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) | 48-133 | 9 | | $36.63 | No

24. Ground | cables (https://falconerelectronics.com/product/ground-wire-9-5-x-green-yellow-8-ga-1-4-stud-to-1-4-stud-rohs/) | 1GY89.5OO 1B | 5 | | $28.31 | No

25. SMA | Female to BNC Male Adapter (https://www.digikey.ca/en/products/detail/rf-solutions/ADP-SMAF-BNCM/4271257) | ADP-SMAF-BNCM | 4 | | $33.64 | No

26. BNC cables | 15 cm (https://www.digikey.ca/en/products/detail/amphenol-rf/115101-19-06-00/2505045) (for VNA testing) | 115101-19-0 6.00 | 4 | | $70.80 | No

27. Test lead | banana to grabber 36’ (https://www.digikey.ca/en/products/detail/pomona-electronics/3782-36-02/736657?gclsrc=aw.ds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) | 3782-36-02 | 6 | | $201.72 | No

28. Olive oil for | phantom (https://www.amazon.ca/Mina-Virgin-Extracted-Moroccan-Polyphenols/dp/B09JCMRY39) | | 1 | Any olive oil from a grocery store could work. | $16.79 | No

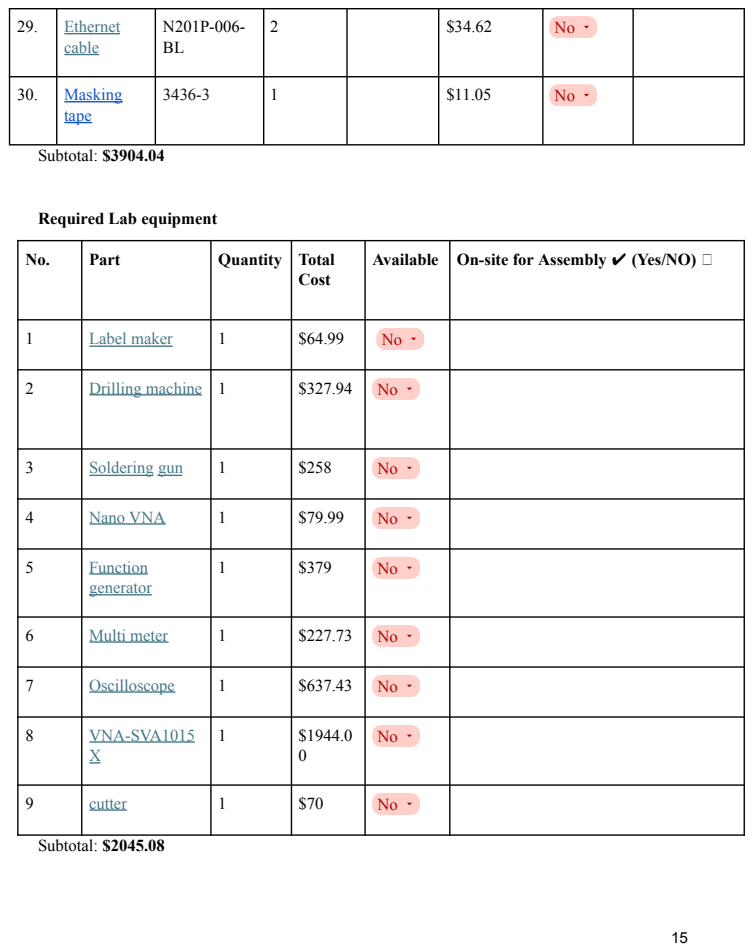
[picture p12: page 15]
Subtotal: $3904.04; Subtotal: $2045.08

29. Ethernet | cable (https://www.digikey.ca/en/products/detail/eaton-tripp-lite/N201P-006-BL/15298306?gclsrc=aw.ds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) | N201P-006-BL | 2 | $34.62 | No

30. Masking | tape (https://www.amazon.ca/Scotch-Office-Masking-3436-3-4-inch/dp/B00347A8E4) | 3436-3 | 1 | $11.05 | No

Required Lab equipment

No. | Part | Quantity | Total Cost | Available | On-site for Assembly ✔ (Yes/NO) 

1 | Label maker (https://www.staples.ca/products/1671378-en-brother-p-touch-ptd210bk-easy-to-use-label-maker) | 1 | $64.99 | No

2 | Drilling machine (https://www.grainger.ca/en/product/p/MTL2606-20?cm_mmc=PPC:+Google+PLA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) | 1 | $327.94 | No

3 | Soldering (https://www.uline.ca/Product/Detail/H-10799/Anti-Static-Equipment/Weller-Soldering-Station?pricode=YO010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) gun | 1 | $258 | No

4 | Nano VNA (https://www.amazon.ca/Seesii-Analyzer-10KHz-1-5GHz-Measuring-Parameters/dp/B08132DJLS) | 1 | $79.99 | No

5 | Function generator (https://www.tequipment.net/Digilent/Analog-Discovery-3/Function-Generator/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) | 1 | $379 | No

6 | Multi meter (https://www.digikey.ca/en/products/detail/fluke-electronics/FLUKE-15B/24398487) | 1 | $227.73 | No

7 | Oscilloscope (https://www.amazon.ca/Rigol-DHO804-Digital-Oscilloscope-Channels/dp/B0CGHQHQN7) | 1 | $637.43 | No

8 | VNA-SVA1015 (https://siglentna.com/product/sva1015x/) X | 1 | $1944.0 0 | No

9 | cutter (https://www.amazon.ca/DEWALT-DWASHRIR-Impact-Shears-Attachment/dp/B01BSAWORC?gad_source=1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) | 1 | $70 | No

Other Important Lab Equipment; Equipment; Part Number; Quantity; Total Cost; Available (Yes/No); Subtotal: $868.95

1. | 3D Printer (https://ca.store.bambulab.com/products/p1s?id=737896686575063052) | 737896686575063052 | 1 | $739 | No
2. PLA Spools (https://ca.store.bambulab.com/products/pla-basic-filament) | (for rings, lids, spacers, and other printed parts) | A00-G6-1.75-1000-SPL | 3 kg (5 spools) 4 green, 1white | $129.95 | No

Other Important Electronics; Electronics; Quantity; Notes; Total Cost; Available (Yes/No)

1. | Pickup coil | 1 | Made from BNC cables. | - No
2. Set of Ceramic Capacitors (https://www.digikey.ca/en/products/detail/kemet/C1812C781KHGLCAUTO/15195497) | (1pF- 800pF) | 50> | Different values of ceramic fixed capacitors to be used during tuning and matching. ( Purchase a | $100 | No

No. | Electronics | Quantity | Notes | Total Cost | Available (Yes/No)
1. | Pickup coil | 1 | Made from BNC cables. | - No
| | | certain quantity depending on your budget)

Grand Total Estimate: $10516.12

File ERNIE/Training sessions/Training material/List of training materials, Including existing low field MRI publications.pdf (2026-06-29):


### Hands-on workshop on building a Simple Low-Field MRI Scanner Training Package

Overview: This workshop is organized by the Low-field Laboratory at the McConnell Brain Imaging Center of the Montreal Neurological Institute in collaboration with the Imaging Without Borders (IMAGINE) (https://event.fourwaves.com/imagine/pages) Summer School. In this interactive 2-hour workshop you will learn the basics of brain magnetic resonance imaging (MRI) hardware. You will assemble a simple MRI scanner, and then measure and characterize its magnetic field using a 3D field-mapping robot that you will build at the workshop.

Prerequisites: No prior hardware experience is needed. Your curiosity and a willingness to learn is all that is required.

Code of Conduct: The workshop is a harassment-free and safe environment for all, regardless of race, cultural affiliation, gender, nationality, beliefs, age, or disability. All participants are expected to comply with this code of conduct and violations of its standards may result in dismissal from the workshop, at the discretion of the workshop organizers. Upholding the standards of behavior is mandatory to maintain the workshop’s integrity and create a positive environment. All participants are expected to behave professionally and responsibly towards everyone during all activities of the workshop, regardless of session.

Workshop Activities: Over the course of the workshop you will engage in:
1. Provide a Photo Use Consent
2. Complete a Pre-training Survey to help improve the workshop for future participants
3. Participate in a Lecture on the Fundamentals of MRI Hardware for low-field brain imaging.
4. Work together to assemble a low-field MRI scanner and an MRI field-mapping system.
5. Assess the field of the low-field MRI scanner you build to see if it provides a good basis to scan brain images at a very low magnetic field.
6. Complete a Post-training Survey to help improve the workshop for future participants.
7. Participate in a Group photo to commemorate this fun experience

Additional Information on Low-Field MRI
Here is more information to help you explore and better understand low-field brain MRI.

Introductory Videos

1. Detailed introductory lecture on MRI by Guillermo - Introductory lecture (https://drive.google.com/file/d/1epqHTyNNhww7lzScqT8hP3_whsnuRLBc/view?usp=drive_link)
2. How to design Halbach array scanner rings with Inventor by Timon- Ring Design (https://drive.google.com/file/d/1LkRrg7XdKk2j7G3yA-qg_bHgM2p8gpHr/view?usp=drive_link)
3. Introductory lecture on MaRCOS by Marina- MaRCOS (https://drive.google.com/file/d/1DxiwVWV5HoG9XZA0nSyDQEECEPj-lpb6/view?usp=drive_link)
4. Introduction to Low-Field MRI by Dr. Johnes- Part 1, (https://drive.google.com/file/d/1Ov1J0vUrpMlnU8uQKgcSz9GquTrUuCi9/view?usp=drive_link) Part 2 (https://drive.google.com/file/d/1j1k53MEtiS-ZotmZZXaTz12UkOKACRbT/view?usp=drive_link)
5. The low-field MRI revolution by Andrew Webb- LF-MRI revolution (https://youtu.be/W3M-wI_rc-0?si=0GU224lwu2aozobm)
6. High ( 56T ), Medium (7T), and Low-field ( 50mT ) by Andrew Webb - HF, MF, LF (https://youtu.be/URVTNamWikU?si=ZV8W-MrNxOsIwyQL)
7. DIY MRI: How to build your own MRI scanner MR by Tom O’Reilly- DIY MRI (https://youtu.be/LS14Q5Zwkdc?si=kAgjm6U6ltqryUh0)
8. OSI

2 ONE: An open-source low-field MRI scanner - OSI

2 ONE (https://youtu.be/KY6X4T3NN3U?si=pLOiTStQ6N6NxzQL)
9. OSI
2 Build Workshop | PTB, Berlin, 22.09.2023- OSI

2 Build (https://youtu.be/1q0dXg17E_w?si=0-mC_I5dyjCIpRf4)
10. MRI4all- MRI together (https://www.youtube.com/embed/qQ7QVIVaeXs?si=--VZ2_hBI6DZcPoZ&start=77)

Relevant Publications
1. Open-source magnetic resonance imaging: Improving access, science, and education through global collaboration- OSI2 publication (https://www.youtube.com/embed/qQ7QVIVaeXs?si=--VZ2_hBI6DZcPoZ&start=77)
2. Design, Characterisation and Performance of an Improved Portable and Sustainable Low-Field MRI System- publication (https://www.frontiersin.org/journals/physics/articles/10.3389/fphy.2021.701157/full)
3. In vivo 3D brain and extremity MRI at 50 mT using a permanent magnet Halbach arraypublication (https://onlinelibrary-wiley-com.proxy3.library.mcgill.ca/doi/full/10.1002/mrm.28396)
4. Tackling SNR at low-field: a review of hardware approaches for point-of-care systemspublication (http://link.springer.com/article/10.1007/s10334-023-01100-3)
5. Low-field MRI: Clinical promises and challenges- publication (https://onlinelibrary-wiley-com.proxy3.library.mcgill.ca/doi/full/10.1002/jmri.28408)
6. On-site construction of a point-of-care low-field MRI system in Africa- publication (https://analyticalsciencejournals.onlinelibrary.wiley.com/doi/full/10.1002/nbm.4917)
7. MRI4all- Publication (https://doi.org/10.1002/jmri.29771)
8. A Hands-On Workshop for Constructing a Low-Field MRI System in Three Days- paper (https://can01.safelinks.protection.outlook.com/?url=https%3A%2F%2Farxiv.org%2Fpdf%2F2511.20979&reserved=0)
9. ezyMRI: How to build an MRI machine from scratch -- Experience from a four-day hackathon- publication (https://arxiv.org/abs/2411.11365)
10. Design of Sparse Halbach Magnet Arrays for Portable MRI Using a Genetic Algorithmpublication (https://www.semanticscholar.org/paper/Design-of-Sparse-Halbach-Magnet-Arrays-for-Portable-Cooley-Haskell/5de7667eb772c6ab244c62b6f1188e0240be917d)
11. In vivo 3D brain and extremity MRI at 50 mT using a permanent magnet Halbach arraypublication (https://onlinelibrary-wiley-com.proxy3.library.mcgill.ca/doi/10.1002/mrm.28396)
12. In-vivo imaging with a low-cost MRI scanner and cloud data processing in low-resource settings- paper (https://arxiv.org/abs/2511.19226)
13. Portable magnetic resonance imaging of patients indoors, outdoors, and at homepublication (https://www.nature.com/articles/s41598-022-17472-w)
14. Elliptical Halbach magnet and gradient modules for low-field portable magnetic resonance imaging- publication (https://analyticalsciencejournals-onlinelibrary-wiley-com.proxy3.library.mcgill.ca/doi/10.1002/nbm.5258)
15. Use of 2.1 MHz MRI scanner for brain imaging and its preliminary results in strokepublication (https://www.sciencedirect.com/science/article/abs/pii/S1090780720301476?getft_integrator=wiley&pes=vor)

16. Electromagnetic Noise Characterization and Suppression in Low-Field MRI Systemspublication (https://onlinelibrary-wiley-com.proxy3.library.mcgill.ca/doi/full/10.1002/mrm.70235)
17. Assessment of Brain Injury Using Portable, Low-Field Magnetic Resonance Imaging at the Bedside of Critically Ill Patients- publication (https://jamanetwork.com/journals/jamaneurology/fullarticle/2769858)
18. A low-cost and shielding-free ultra-low-field brain MRI scanner- publication (https://www.nature.com/articles/s41467-021-27317-1)
19. A Low-Field Portable MRI Scanner With an Elliptic-Bore Halbach Magnet- publication (https://scholar.google.com/scholar?hl=en&as_sdt=0%2C5&btnG=)

Open source hardware libraries
1. Halbach Ring Magnetic Field Optimization- git-hub (https://github.com/tmachtelinckx/halbacharray-GA)
2. Field mapper robot- git-hub (https://github.com/SipanHovsep/Field_mapper_robot)
3. Imaging without boarders- git-hub (https://github.com/CAMERA-MRI/IMAGINE/tree/main)
4. ERNIE
5. Open Source Imaging Initiative- OSI

2 (https://gitlab.com/osii)
6. MRI4all - MRI4all (https://github.com/mri4all)
7. Halbach MRI Designer - github (https://github.com/menkueclab/HalbachMRIDesigner)
8. Delta-DIY-MRI- git-hub (https://github.com/delta-diy-mri/delta-diy-mri.github.io/wiki/2025-workshop-program)
9. LUMC - git-hub (https://github.com/LUMC-LowFieldMRI)
10. OSII MRI- git-hub (https://github.com/LilisProtoLab/osii_MRI)

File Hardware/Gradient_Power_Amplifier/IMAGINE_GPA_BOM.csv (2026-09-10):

Gradient Power Amplifier (FHDO-GPA) for image generation
No. | Part name | Part Number | Name or code on PCB board | Quantity | Total Cost (Canadian dollars) | 3D Printed (Yes/No) | Added to Assembly ?/ Not yet added to the Assembly?? | Disassembled ?/ Not yet Disassembled??
 | Active components
1 | 4 channel 16 bit ADC | ADS8684IDBTR | U5 | 1 | $23.11 | No
2 | RJ-45 connector | 609-146-ND | X4 | 2 | $2.28 | No
3 | Inverter | MC74HC1G04DTT1GOSCT-ND | U20 | 1 | $0.16 | No
4 | Power supply connector | WM 21 367-ND | VCC | 1 | $7.52 | No
5 | Power supply connector plug | WM-37-04-ND |  | 1 | $0.69 | No
6 | 12 volt- voltage regulator | 497-7767-1-ND | U7 | 1 | $0.47 | No
7 | 5 volt-voltage regulator | 497-2957-5-ND | U21 | 1 | $1.61 | No
8 | Heatsink | HS-343-ND | U100, U101, U102, U103 | 4 | $33.48 | No
9 | 2.5 volt reference | 296-39165-1-ND | U22 | 1 | $6.84 | No
10 | power amplifier | OPA549T-ND | U8, U9, U11, U12, U17, U18, U23, U24 | 8 | $430.80 | No
11 | Coil connectors output of amplifier to grad coil | WM-13112 |  | 4 | $9.36 | No
12 | Coil connector plug | WM 3701-ND |  | 4 | $1.80 | No
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

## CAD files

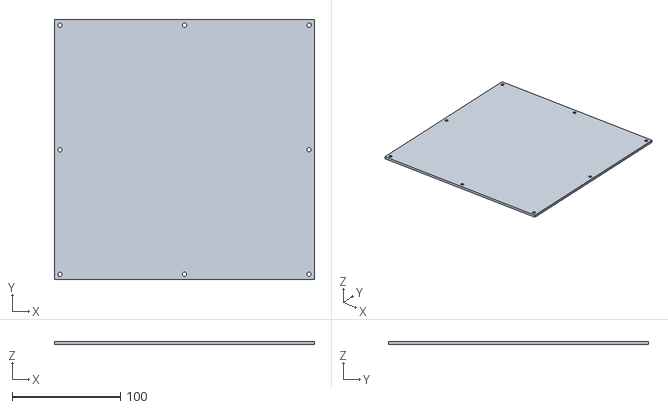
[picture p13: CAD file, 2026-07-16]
ERNIE/Build your own Design/Magnet/Scanner disassembly/Disassembly Tray_Cover.stl
240.0 x 240.0 x 3.00

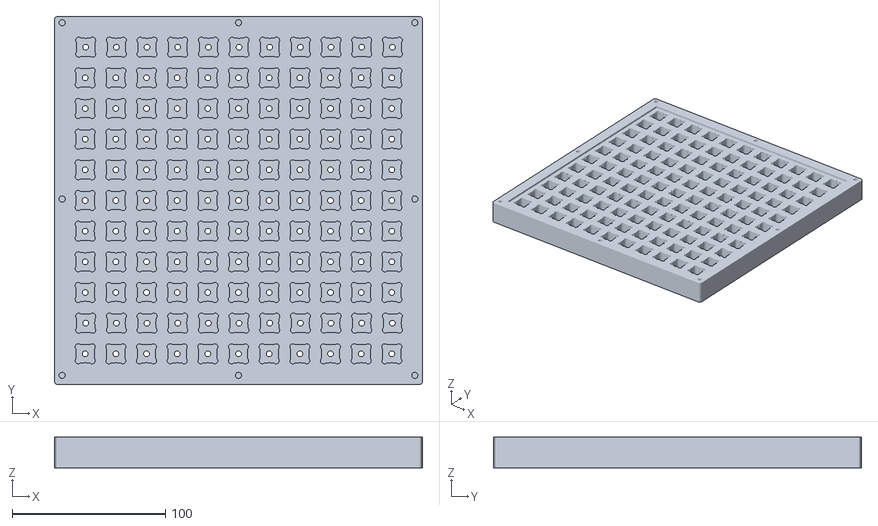
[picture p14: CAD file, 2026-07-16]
ERNIE/Build your own Design/Magnet/Scanner disassembly/Disassembly Tray.stl
240.0 x 240.0 x 20.0

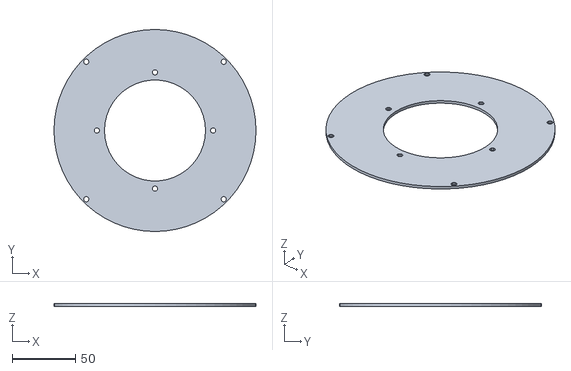
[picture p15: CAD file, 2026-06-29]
ERNIE/Build your own Design/Magnet/Scanner parts for 3D printing/ERNIE 1&2 rings and lids (.stl)/Lid_For_Ring_321.stl
160.0 x 160.0 x 2.00

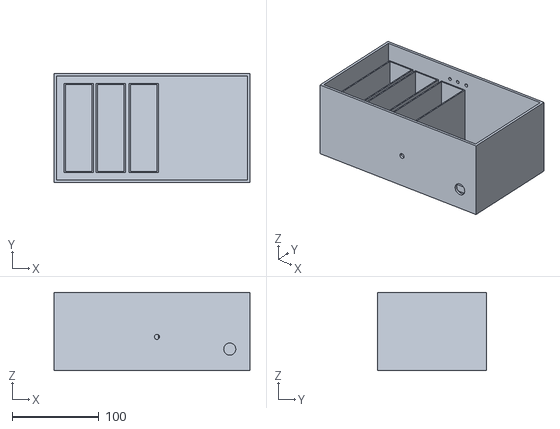
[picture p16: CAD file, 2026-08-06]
ERNIE/Build your own Design/Magnet/Scanner parts for 3D printing/Motor Driver Casing.stl
226.0 x 126.0 x 90.5

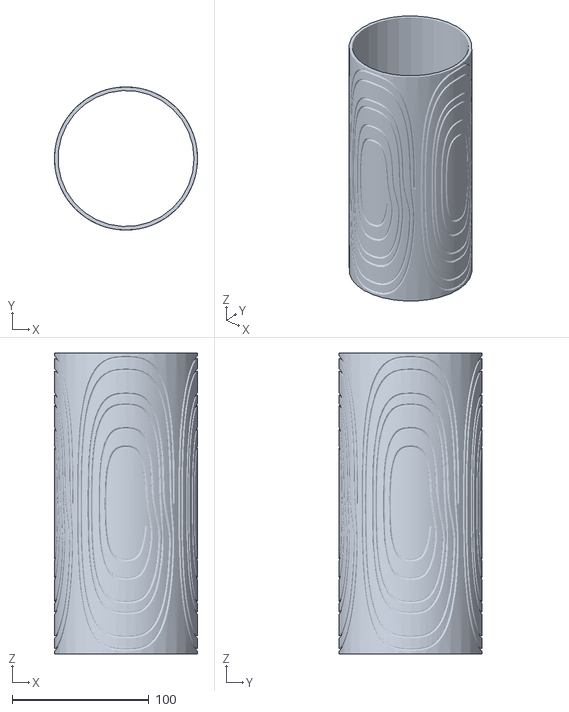
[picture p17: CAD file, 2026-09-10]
Hardware/Gradients/CAD/X_Gradient_Coil_Former_Rat_Scanner.stl
104.6 x 104.6 x 220.0

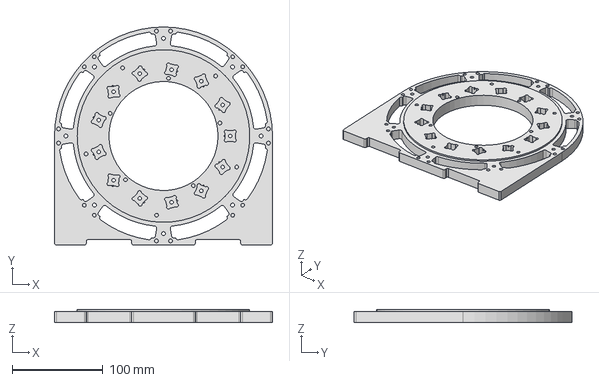
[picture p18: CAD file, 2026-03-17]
Hardware/Halbach Array/STP Files/Ring_10_front.stp
240.0 x 240.0 x 14.0 mm

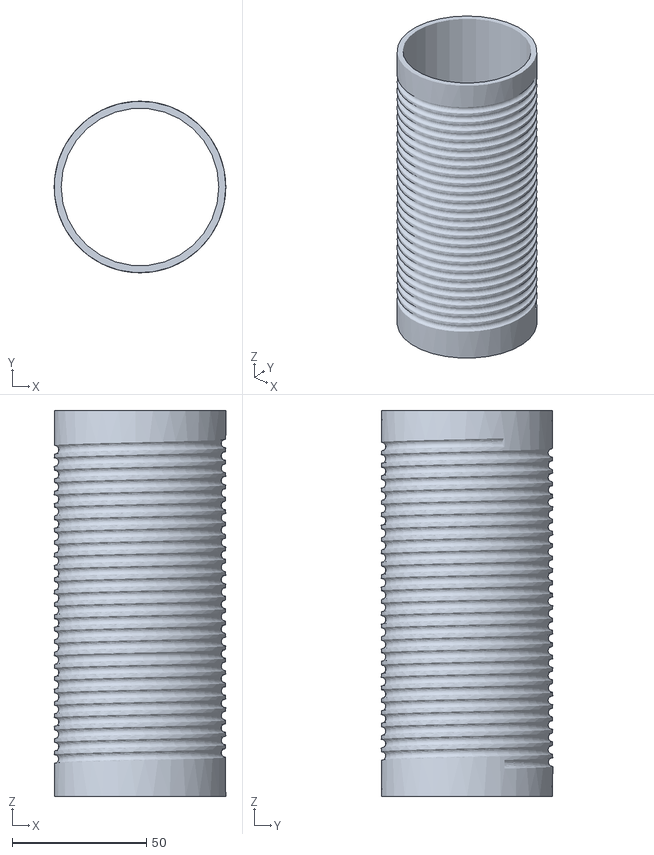
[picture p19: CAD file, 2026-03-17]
Hardware/RF coil/RF COIL with 27 turns, inner diameter 58.8mm.stl
64.0 x 64.0 x 144.0

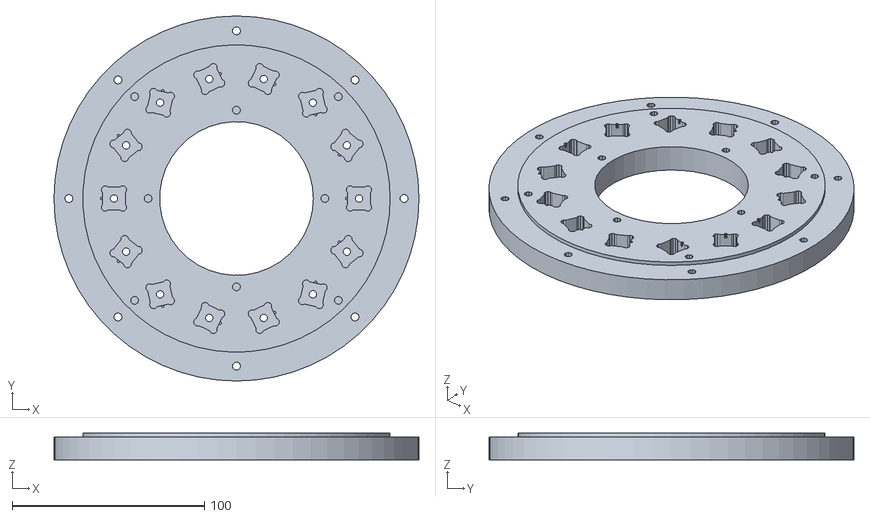
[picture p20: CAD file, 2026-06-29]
ERNIE/Build your own Design/Magnet/Scanner parts for 3D printing/ERNIE 1&2 rings and lids (.stl)/Ring 288.stl
190.0 x 190.0 x 14.0

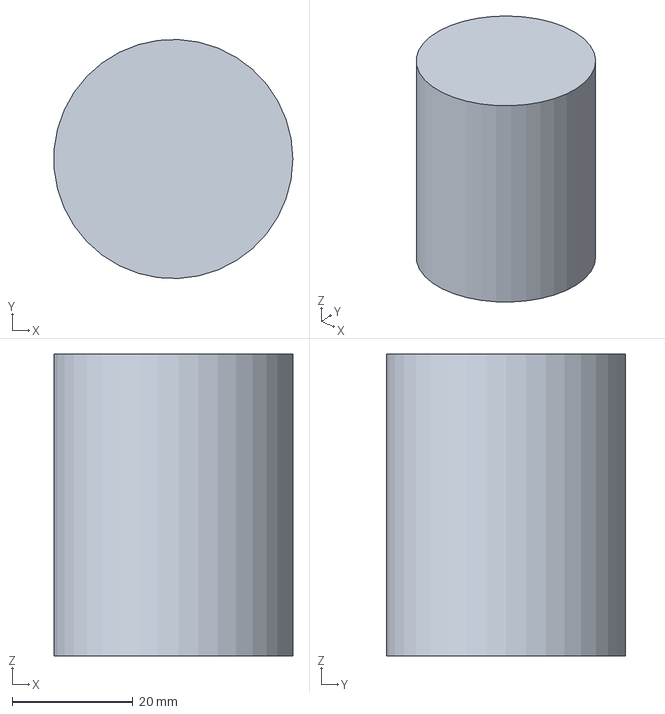
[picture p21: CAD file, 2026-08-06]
ERNIE/Build your own Design/Magnet/Scanner parts for 3D printing/Phantom_18AWG.3mf
39.5 x 39.6 x 50.0 mm

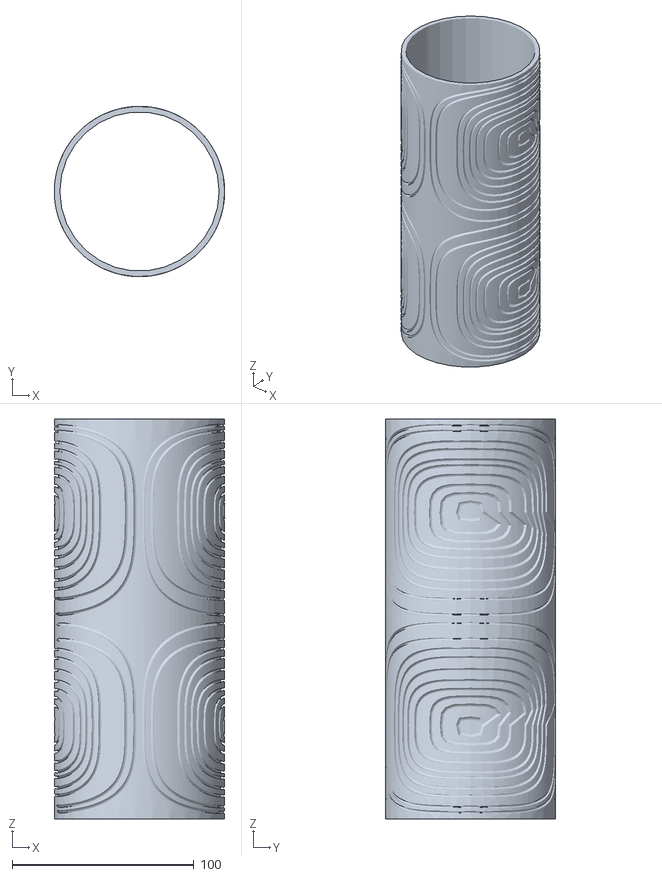
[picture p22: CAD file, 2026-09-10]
Hardware/Gradients/CAD/Z_Gradient_Coil_Former_Rat_Scanner.stl
93.7 x 93.7 x 220.0

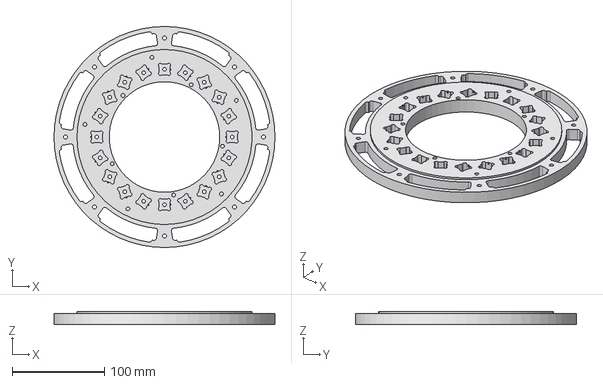
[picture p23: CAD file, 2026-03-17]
Hardware/Halbach Array/STP Files/Ring_1.stp
240.0 x 240.0 x 14.0 mm

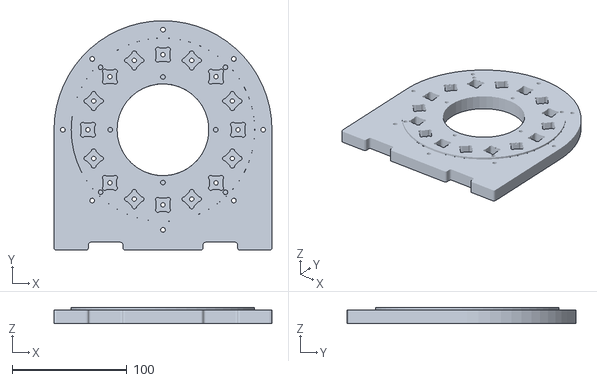
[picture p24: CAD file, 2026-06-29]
ERNIE/Build your own Design/Magnet/Scanner parts for 3D printing/ERNIE 1&2 rings and lids (.stl)/Ring 321 (105mm_length).stl
190.0 x 200.0 x 14.0

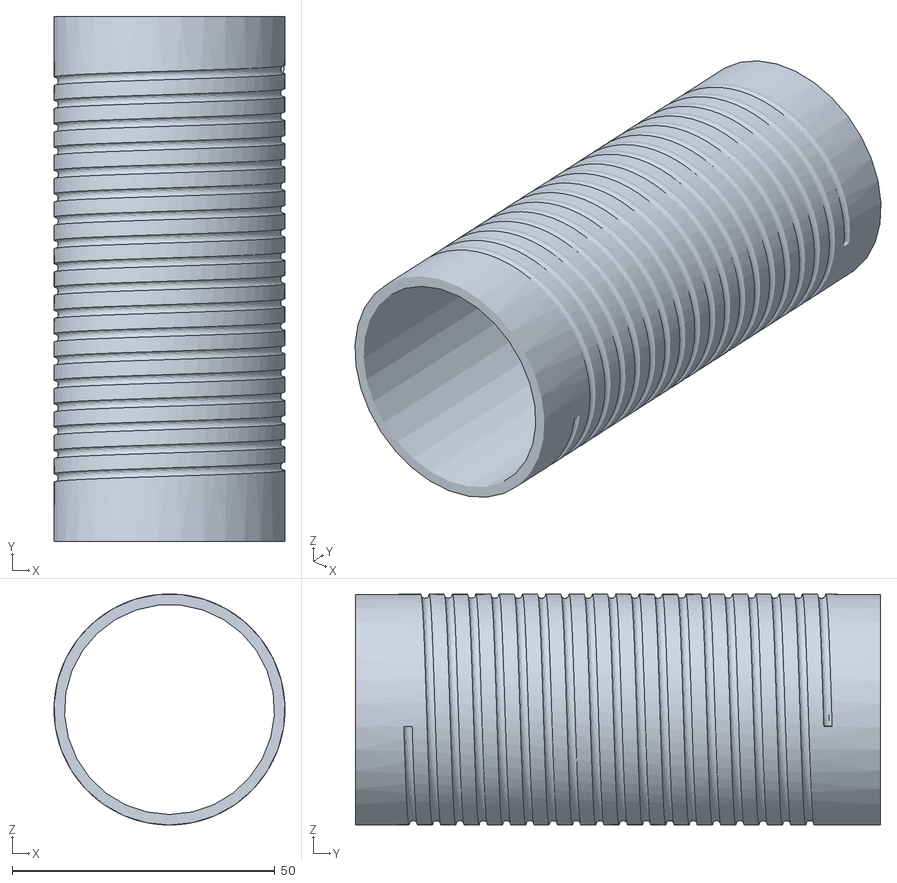
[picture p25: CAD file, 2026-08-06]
ERNIE/Build your own Design/Magnet/Scanner parts for 3D printing/RF_Coil.stl
44.0 x 100.0 x 44.0

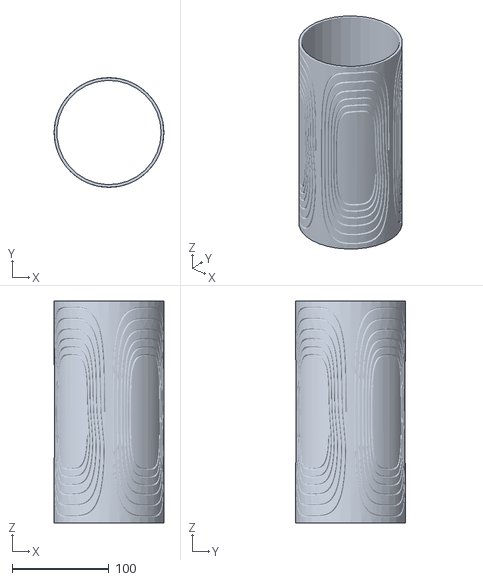
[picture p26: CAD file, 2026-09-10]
Hardware/Gradients/CAD/Y_Gradient_Coil_Former_Rat_Scanner.stl
113.6 x 113.6 x 230.0

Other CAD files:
Hardware/Halbach Array/STP Files/Ring_0.stp
ERNIE/Build your own Design/Magnet/Scanner parts for 3D printing/ERNIE 1&2 rings and lids (.stl)/Lid_For_Ring_42.stl
ERNIE/Build your own Design/Magnet/Scanner parts for 3D printing/Scanner Base for field mapping.stl
Hardware/Halbach Array/STP Files/Ring_842.stp
ERNIE/Build your own Design/Magnet/Scanner parts for 3D printing/ERNIE 1&2 rings and lids (.stl)/Lid_For_Rings 288 and 251.stl
ERNIE/Build your own Design/Magnet/Scanner parts for 3D printing/ERNIE 1&2 rings and lids (.stl)/Ring 251.stl
ERNIE/Build your own Design/Magnet/Scanner parts for 3D printing/ERNIE 1&2 rings and lids (.stl)/Ring 42 (105mm_length ).stl
ERNIE/Build your own Design/Magnet/Scanner parts for 3D printing/ERNIE 1&2 rings and lids (.stl)/Ring_spacers.stl
ERNIE/Build your own Design/Magnet/Scanner parts for 3D printing/Ernie_RF Coil base.stl
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

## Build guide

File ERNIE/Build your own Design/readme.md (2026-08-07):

# Build your own Design
## Overview

<p style="text-align: justify;">
  This section includes;
  
  [Magnet](https://github.com/CAMERA-MRI/IMAGINE/tree/main/ERNIE/Build%20your%20own%20Design/Magnet) ,
  [Robot](https://github.com/CAMERA-MRI/IMAGINE/tree/main/ERNIE/Build%20your%20own%20Design/Robot)
  and List of parts, bill of materials required to assemble the magnet, robot and obtain a signal
  <b> <b>
 <p align="center">
 build your own design
  </p>
</p>
</p>

# 📦 ERNIE Toolkit – Bill of Materials (BOM)

This document contains the complete list of components, tools, and equipment required to assemble the **ERNIE educational low-field MRI toolkit**.

---

# 🧳 Carrying Case

| No. | Part | Part Number | Notes | Qty. | Total Cost (CAD) | 3D Printed | On-site for Assembly |
|:---:|---|---|---|:---:|:---:|:---:|:---:|
| 1 | | Case (Used to carry tools and parts to the assembly site) | [Travel Suitcase (Amazon)](https://www.amazon.ca/Atlantic-Acclaim-Hardside-Spinner-20-Inch/dp/B09LZNQLB9) or [NANUK 935 Waterproof Hard Case with Wheels](https://www.amazon.ca/Nanuk-Waterproof-Hard-Wheels-Empty/dp/B00BP8UL9Q)  | | AL21769009 | 1 | **$90.55** | ❌ | ☐ |

**Subtotal:** **$90.55**

---

# 🧲 Magnet

| No. | Part | Part Number | Notes | Qty. | Total Cost (CAD) | 3D Printed | Added to Assembly | Disassembled |
|:---:|---|---|---|:---:|:---:|:---:|:---:|:---:|
| 1 | [Ring 42](https://github.com/CAMERA-MRI/IMAGINE/blob/main/ERNIE/Build%20your%20own%20Design/Magnet/Scanner%20parts%20for%203D%20printing/ERNIE%201%262%20rings%20and%20lids%20(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) | — | Approximately **134 g PLA** per ring | 2 | — | ✅ | ☐ | ☐ |
| 2 | [Ring 251](https://github.com/CAMERA-MRI/IMAGINE/blob/main/ERNIE/Build%20your%20own%20Design/Magnet/Scanner%20parts%20for%203D%20printing/ERNIE%201%262%20rings%20and%20lids%20(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) | — | Approximately **134 g PLA** per ring | 2 | — | ✅ | ☐ | ☐ |
| 3 | [Ring 288](https://github.com/CAMERA-MRI/IMAGINE/blob/main/ERNIE/Build%20your%20own%20Design/Magnet/Scanner%20parts%20for%203D%20printing/ERNIE%201%262%20rings%20and%20lids%20(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) | — | Approximately **134 g PLA** per ring | 2 | — | ✅ | ☐ | ☐ |
| 4 | [Ring 321](https://github.com/CAMERA-MRI/IMAGINE/blob/main/ERNIE/Build%20your%20own%20Design/Magnet/Scanner%20parts%20for%203D%20printing/ERNIE%201%262%20rings%20and%20lids%20(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) | — | Approximately **134 g PLA** per ring | 1 | — | ✅ | ☐ | ☐ |
| 5 | [Lid for Ring 42](https://github.com/CAMERA-MRI/IMAGINE/blob/main/ERNIE/Build%20your%20own%20Design/Magnet/Scanner%20parts%20for%203D%20printing/ERNIE%201%262%20rings%20and%20lids%20(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)| — | Approximately **45 g PLA** each | 2 | — | ✅ | ☐ | ☐ |
| 6 | [Lid for Ring 251](https://github.com/CAMERA-MRI/IMAGINE/blob/main/ERNIE/Build%20your%20own%20Design/Magnet/Scanner%20parts%20for%203D%20printing/ERNIE%201%262%20rings%20and%20lids%20(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) | — | Approximately **45 g PLA** each | 2 | — | ✅ | ☐ | ☐ |
| 7 | [Lid for Ring 288](https://github.com/CAMERA-MRI/IMAGINE/blob/main/ERNIE/Build%20your%20own%20Design/Magnet/Scanner%20parts%20for%203D%20printing/ERNIE%201%262%20rings%20and%20lids%20(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) | — | Approximately **45 g PLA** each | 2 | — | ✅ | ☐ | ☐ |
| 8 | [Lid for Ring 321](https://github.com/CAMERA-MRI/IMAGINE/blob/main/ERNIE/Build%20your%20own%20Design/Magnet/Scanner%20parts%20for%203D%20printing/ERNIE%201%262%20rings%20and%20lids%20(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) | — | Approximately **45 g PLA** | 1 | — | ✅ | ☐ | ☐ |
| 9 | [180 mm Brass Rods (McMaster-Carr)](https://www.mcmaster.com/catalog/131/3633/90162A050) | 90162A050 | Purchase two 1 m rods, and cut each 1m rod into 5 **180 mm** rods. | 8 | **$39.54** | ❌ | ☐ | ☐ |
| 10 | [Ring Spacers](https://github.com/CAMERA-MRI/IMAGINE/blob/main/ERNIE/Build%20your%20own%20Design/Magnet/Scanner%20parts%20for%203D%20printing/ERNIE%201%262%20rings%20and%20lids%20(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) | — | Approximately **100 g PLA** required for 80 spacers | 48 | — | ✅ | ☐ | ☐ |
| 11 | [M4 Brass Nuts (Amazon)](https://www.amazon.ca/100pcs-Solid-Brass-Copper-Screw/dp/B0CQGYC7JZ) | B0CQGYC7JZ | Pack of 50 | 8 | **$11.33** | ❌ | ☐ | ☐ |
| 12 | [M3 Brass Screws (Amazon)](https://www.amazon.ca/dp/B0CT3W8148) | a23122400ux0074 | Brass screws are preferred (60/pack) | 54 | **$13.99** | ❌ | ☐ | ☐ |
| 13 | [Dome-shaped Nuts (M4, McMaster-Carr)](https://www.mcmaster.com/products/dome-nuts/thread-size~m4/) | 90527A505 | Pack of 100 | 8 | **$22.96** | ❌ | ☐ | ☐ |
| 14 |[M4 Nylon Washers (McMaster-Carr)](https://www.mcmaster.com/catalog/131/3696/95610A150) | 95610A150 | Pack of 100 | 16 | **$7.70** | ❌ | ☐ | ☐ |
| 15 | [Neodymium Magnets](https://www.magfine.ca/products/neodymium-magnet-square-13mm-x-12mm-x-5mm)  | — | Specify dimensions (12 × 12 × 12 mm) to supplier | 98 | **$575.26** | ❌ | ☐ | ☐ |
| 16 | Reference Neodymium Magnets | — | Made from no.15_ [Neodymium Magnets](https://www.magfine.ca/products/neodymium-magnet-square-13mm-x-12mm-x-5mm)  | 4 | **$23.48** | ❌ | ☐ | ☐ |
| 17 | [M3 Brass Heat-set Inserts (Amazon)](https://www.amazon.ca/dp/B0DC43HJKN) | a24062300ux0395 | Pack of 100 | 54 | **$17.69** | ❌ | ☐ | ☐ |
| 18 | [PLA Basic Filament (Bambu Lab)](https://ca.store.bambulab.com/products/pla-basic-filament?variant=541209412732915753) / PETG / ABS | — | Color of your choice | 4 | **$25.99** | ❌ | ☐ | ☐ |

**Subtotal:** **$737.94**

---

# 🧲 Spare Magnets

| No. | Part | Notes | Qty. | Total Cost (CAD) | 3D Printed | On-site for Assembly |
|:---:|---|---|:---:|:---:|:---:|:---:|
| 1 | [Neodymium Magnets (12 mm × 12 mm × 12 mm, Magfine)](https://www.magfine.ca/products/neodymium-magnet-square-13mm-x-12mm-x-5mm) | Replacement magnets for damaged units made from no.15 above | 10 | **$58.70** | ❌ | ☐ |

**Subtotal:** **$58.70**

---

# 🔧 Tools Required for Magnet Assembly

| No. | Tool | Part Number | Notes | Qty. | Total Cost (CAD) | Available | Returned to Box |
|:---:|---|---|---|:---:|:---:|:---:|:---:|
| 1 | [Screwdriver Set (Amazon)](https://www.amazon.ca/13-Pieces-Screwdrivers-Screwdriver-Magnetizer-demagnetizer/dp/B0CXSYBCXW) | 06973932450615 | Cross-head (Phillips) with comfortable grip | 4 | **$20.99** | ☐ | ☐ |
| 2 | [Spanners (Amazon)](https://www.amazon.ca/gp/product/B0DXPGQL98) | hta250106hh001215 | 7 mm open wrench | 2 | **$25.59** | ☐ | ☐ |
| 3 | [Compass (Suunto MCB NH Mirror Compass, Amazon)](https://www.amazon.ca/Suunto-SS012277013-MCB-Black-Compass/dp/B002FA9GYE) | — | Standard compass | 2 | **$54.99** | ☐ | ☐ |
| 4 | [Permanent Markers (Sharpie, Amazon)](https://www.amazon.ca/Sharpie-Permanent-4-Carded-Assorted-35113PP/dp/B000GOZXA2) | SAN35113PP | Colors red, black or blue | 4 | **$13.78** | ☐ | ☐ |
| 5 | [Vernier Caliper (Kynup, Amazon)](https://www.amazon.ca/Kynup-Measuring-Stainless-Waterproof-Protection/dp/B07X8JQ8L5) | USQC03301915 | 6-inch caliper | 1 | **$34.99** | ☐ | ☐ |
| 6 | [Ruler](https://www.amazon.ca/Transparent-Measuring-Suitable-Childrens-Centimeter/dp/B09B6V3PGM) | — | Non-magnetic 30cm ruler | 1 | **$6.69** | ☐ | ☐ |

**Subtotal:** **$157.03**

---
---

# 🤖 Robot Assembly

| No. | Part | Part Number | Qty. | Notes | Total Cost (CAD) | 3D Printed | Added to Assembly | Disassembled |
|:---:|---|---|:---:|---|:---:|:---:|:---:|:---:|
| 1 | [Magnet Rails](https://www.aliexpress.com/item/1005005534966065.html) (Set of 3) | T06 | 3 | X, Y, and Z rails should each be **150 mm** long. | **$273.78** | ❌ | ☐ | ☐ |
| 2 | M4 & M3 Screws | — | 8 | Included with the rails | — | ❌ | ☐ | ☐ |
| 3 | [Arduino Uno R4 Minima](https://thepihut.com/products/arduino-uno-r4-minima) | ABX00080 | 1 | Arduino Uno development board | **$33.50** | ❌ | ☐ | ☐ |
| 4 | [Motor Drivers](https://www.aliexpress.com/item/1005005967708477.html) | — | 3 | Stepper motor drivers | **$34.62** | ❌ | ☐ | ☐ |
| 5 | [Motor Driver + Arduino Casing](https://github.com/CAMERA-MRI/IMAGINE/blob/main/ERNIE/Build%20your%20own%20Design/Magnet/Scanner%20parts%20for%203D%20printing/Motor%20Driver%20Casing.stl) | — | 1 | PLA printed | — | ✅ | ☐ | ☐ |
| 6 | [Scanner Base for Field Mapping](https://github.com/CAMERA-MRI/IMAGINE/blob/main/ERNIE/Build%20your%20own%20Design/Magnet/Scanner%20parts%20for%203D%20printing/Scanner%20Base%20for%20field%20mapping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) | — | 4 | PLA printed | — | ✅ | ☐ | ☐ |
| 7 | [Connecting Wires](https://www.amazon.ca/TUOFENG-Hookup-Wires-6-Different-Colored/dp/B0CM2Y7V1Z) | 22 AWG | 25 | Cut to required lengths | **$23.99** | ❌ | ☐ | ☐ |
| 8 |[DC Power Supply](https://www.amazon.ca/dp/B0B9XGQQSR)| CA-24V-3A-72W | 1 | 24 V, 3 A | **$22.99** | ❌ | ☐ | ☐ |
| 9 | [Laptop](https://www.amazon.ca/dp/B0GMV73BNZ) | HP 15 | 1 | Install Ubuntu to run MaRGE | **$689.99** | ❌ | ☐ | ☐ |
| 10 | [Gauss Meter (AlphaLab GM2)](https://www.alphalabinc.com/products/gm2/) | GM2 | 1 | Magnetic field measurement | **$1200.00** | ❌ | ☐ | ☐ |
| 11 | [Gauss Meter Probe Holder (STL)](https://github.com/SipanHovsep/Field_mapper_robot/blob/main/3D%20print%20files/Sensor_mount_1.stl) | — | 1 | PLA printed | — | ✅ | ☐ | ☐ |
| 12 | [Gauss Meter Probe Calibrator (Zero Gauss Chamber)](https://www.alphalabinc.com/products/zgc/) | ZGC | 1 | Accessory for the GM2 | **$196.00** | ❌ | ☐ | ☐ |
| 13 | [Gauss Meter Casing (Hard Carrying Case for GM2)](https://www.alphalabinc.com/products/hc-gm2/) | HC-GM2 | 1 | Protective enclosure | **$33.00** | ❌ | ☐ | ☐ |
| 14 | [Gauss Meter Batteries (Interstate DRY0196 9V)](https://www.amazon.ca/Interstate-Batteries-DRY0196-9v-battery_single-use/dp/B00LZ5NCC2) | DRY0196 | 1 Set (12) | Replacement batteries | **$35.43** | ❌ | ☐ | ☐ |

**Subtotal:** **$2,543.30**

---

# 🛠️ Tools Required for Robot Assembly

| No. | Tool | Part Number | Qty. | Notes | Total Cost (CAD) | Available | Returned to Box |
|:---:|---|---|:---:|---|:---:|:---:|:---:|
| 1 | [Screwdrivers (Amazon)](https://www.amazon.ca/Screwdriver-Adjustable-Multitool-Security-Phillips/dp/B09XV7P17T) | SD013E-Red | 2| Flat-head screwdrivers preferred| **$33.98** | ☐ | ☐ |
| 2 | [Allen Keys (Hex Key Set)](https://www.amazon.ca/Metric-Extension-Impact-Driver-Repair/dp/B0F2HB6K22) (Hex Bit Set) | — | 4 | Hex bit set | **$25.98** | ☐ | ☐ |
| 3 | [Masking Tape](https://www.amazon.ca/AmazonBasics-Masking-Tape-Inch-Rolls/dp/B07QHSKGMH) | AB506-3 | 1 | General assembly use | **$9.05** | ☐ | ☐ |

**Subtotal:** **$69.01**

> **Note:** Screwdrivers are already listed under **Tools Required for Magnet Assembly**.

---

# 🔩 Magnet Disassembly

| No. | Part | Part Number | Qty. | Notes | Total Cost (CAD) | Available | On-site for Assembly |
|:---:|---|---|:---:|---|:---:|:---:|:---:|
| 1 | [Magnet Ouster (Wooden Chopsticks)](https://www.amazon.ca/Heiwa-Wooden-Chospticks-Pairs-Pack/dp/B07B6LP24M) | 871392000899 | 1 | Sharpen to push magnets out of the rings safely | **$11.54** | ☐ | ☐ |
| 2 |[3D Printed Disassembly Tray)](https://github.com/CAMERAMRI/IMAGINE/blob/main/ERNIE/Build%20your%20own%20Design/Magnet/Scanner%20disassembly/Disassembly%20Tray.stl) | — | 1 | PLA printed | — | ✅ | ☐ |
| 3 | [3D Printed Disassembly Tray Cover)](https://github.com/CAMERA-MRI/IMAGINE/blob/main/ERNIE/Build%20your%20own%20Design/Magnet/Scanner%20disassembly/Disassembly%20Tray_Cover.stl)  | — | 1 | 3D printed | — | ✅ | ☐ |
| 4 | [Cutter Knife](https://www.amazon.ca/TIFICAL-Retractable-Snap-Off-Wrapping-Cardboard/dp/B0D634MZ99) | 016392515244 | 1 | Used for sharpening the magnet ouster | **$8.99** | ☐ | ☐ |
| 5 | [M3 Brass Heat-set Inserts](https://www.amazon.ca/dp/B0DC43HJKN) | a24062300ux0395 | 9 | Same inserts used in the magnet rings | — | ☐ | ☐ |
| 6 | [Non-magnetic Brass Screws](https://www.amazon.ca/dp/B0CT3W8148) | — | 9 | Same screws used for the magnet rings | — | ☐ | ☐ |

**Subtotal:** **$20.53**

---
## Works in Progress (Optional) ##

<p style="text-align: justify;">
  
The current stage of ERNIE development focuses on the assembly and validation of the magnet and robotic components. Following assembly, the robot is used to perform magnetic field mapping of the scanner to characterize the field distribution.

</p>

<p style="text-align: justify;">
  
Beyond mechanical assembly and field characterization, integration of the required electronics and instrumentation enables the ERNIE toolkit to generate and acquire MRI signals. Using the equipment described in the preceding tables, signal acquisition was successfully demonstrated, with an example signal shown below.

</p>

<p align="center">
Signal
</p>

---

# 📡 Electronics Required for Signal Generation

| No. | Component | Part Number | Qty. | Notes | Total Cost (USD) | Available | On-site for Assembly |
|:---:|---|---|:---:|---|:---:|:---:|:---:|
| 1 | [Red Pitaya SDRlab 122-16 Standard Kit](https://redpitaya.com/product/sdrlab-122-16-standard-kit/) | IZD0021 | 1 | MaRCoS Compatible | **$1,234.65** | ☐ | ☐ |
| 2 | [RF Power Amplifier (RFPA) - Mini-Circuits ZX60-100VH+](https://www.mouser.ca/ProductDetail/Mini-Circuits/ZX60-100VH%2B) | ZX60-100VH+ | 1 | RF transmit amplifier | **$476.28** | ☐ | ☐ |
| 3 | [RF Preamplifier (LNA)](https://drive.google.com/file/d/1gmChqRjbeQmWzP2a9IR3v9yzpgMjObmQ/view) | ABL0050-00-4510 | 1 | Narrow-band NMR preamplifier may also be used | **$397.60** | ☐ | ☐ |
| 4 | [RFPA Power Supply (SRA KD3005D)](https://www.digikey.ca/en/products/detail/sra-soldering-products/KD3005D/10709902) | 2260-KD3005D | 1 | 12 V, 300 mA | **$138.04** | ☐ | ☐ |
| 5 | [LNA Power Supply (SRA KD3005D)](https://www.digikey.ca/en/products/detail/sra-soldering-products/KD3005D/10709902) | 2260-KD3005D | 1 | 12 V, 100 mA | **$138.04** | ☐ | ☐ |
| 6 |[Passive TR Switch](https://gitlab.com/osii/rf-system/tr-switches/passive-tr-switch)| — | 1 | PCB fabricated following the OSI² TR switch design | **$100.00** | ☐ | ☐ |
| 7 |[RF Coil](https://github.com/CAMERA-MRI/IMAGINE/blob/main/ERNIE/Build%20your%20own%20Design/Magnet/Scanner%20parts%20for%203D%20printing/RF_Coil.stl)| — | 1 | RF transmit/receive coil | — | ☐ | ☐ |
| 8 | [RF Coil Base](https://github.com/CAMERA-MRI/IMAGINE/blob/main/ERNIE/Build%20your%20own%20Design/Magnet/Scanner%20parts%20for%203D%20printing/Ernie_RF%20Coil%20base.stl)) | — | 1 | PLA printed | — | ☐ | ☐ |
| 9 | [Copper Enamelled Wire (Magnet Wire)](https://www.digikey.ca/en/products/detail/cnc-tech/610216/4924215) | — | 1 | For winding RF coils | **$211.28** | ☐ | ☐ |
| 10 | [Variable Tuning & Matching Capacitor (Passive Plus PPZN30100)](https://www.digikey.ca/en/products/detail/passive-plus/PPZN30100/19235833) | PPZN30100 | 2 | Used together with fixed capacitors | **$156.94** | ☐ | ☐ |
| 11 | [Phantom Holder](https://github.com/CAMERA-MRI/IMAGINE/blob/main/ERNIE/Build%20your%20own%20Design/Magnet/Scanner%20parts%20for%203D%20printing/Phantom_18AWG.3mf) | — | 1 | Fill cylindrical phantom holder with olive oil | — | ☐ | ☐ |
| 12 | [Olive Oil (Mina Extra Virgin Olive Oil)](https://www.amazon.ca/Mina-Virgin-Extracted-Moroccan-Polyphenols/dp/B09JCMRY39) | — | 1 | Phantom filling | **$16.79** | ☐ | ☐ |
| 13 | [SMA Cables (TE Connectivity Linx CSE-SGAM-305-SGAM)](https://www.digikey.ca/en/products/detail/te-connectivity-linx/CSE-SGAM-305-SGAM/14633985) | CSE-SGAM-305-SGAM | 12 | Purchase approximately 20 or more | **$146.76** | ☐ | ☐ |
| 14 | [SMA Female–Female Adapter (GCT RFAD-SA3SA2-01-N-A)](https://www.digikey.ca/en/products/detail/gct/RFAD-SA3SA2-01-N-A/25819955)| RFAD-SA3SA2-01-N-A | 8 | SMA adapters | **$43.76** | ☐ | ☐ |
| 15 | [Aluminum Enclosure (LNA) - Bud Industries CU-234](https://www.digikey.ca/en/products/detail/bud-industries/CU-234/387028) | CU-234 | 1 | Shielded enclosure | **$19.33** | ☐ | ☐ |
| 16 | [Aluminum Enclosure (RFPA) - Bud Industries CU-234](https://www.digikey.ca/en/products/detail/bud-industries/CU-234/387028) | CU-234 | 1 | Shielded enclosure | **$19.33** | ☐ | ☐ |
| 17 | [Aluminum Enclosure (Red Pitaya & FHDO) - Hammond Manufacturing 1590Z166](https://www.digikey.ca/en/products/detail/hammond-manufacturing/1590Z166/1090767) | 1590Z166 | 1 | Electronics enclosure | **$223.13** | ☐ | ☐ |
| 18 | [Aluminum Enclosure (Passive TR Switch) - Bud Industries CU-234](https://www.digikey.ca/en/products/detail/bud-industries/CU-234/387028) | CU-234 | 1 | Shielded enclosure | **$19.33** | ☐ | ☐ |
| 19 | [Aluminum Enclosure (Matching Circuit) - Bud Industries CU-234](https://www.digikey.ca/en/products/detail/bud-industries/CU-234/387028) | CU-234 | 1 | Shielded enclosure | **$19.33** | ☐ | ☐ |
| 20 |[Aluminum Sheet](https://www.amazon.ca/Bilaida-Stainless-Roll%EF%BC%8C0-2mm-Electronic-Equipment/dp/B0DKWH3DB7) | BSS-00903 | 1 | Scanner RF shielding | **$43.30** | ☐ | ☐ |
| 21 |[Copper Sheet](https://www.amazon.ca/dp/B0CDGQ95YB) | 60 | 1 | Internal RF shield connected to ground | **$30.99** | ☐ | ☐ |
| 22 | [Copper Tape (Conductive Shielding Tape)](https://www.amazon.ca/Single-Sided-Conductive-Shielding-Repellent-Electrical/dp/B083QJDQ5M)| B083QJDQ5M | 1 | Joins copper shielding | **$12.59** | ☐ | ☐ |
| 23 | [Aluminum Tape (3M 1436 Aluminum Foil Tape)](https://canada.newark.com/3m/1436-50mm/tape-aluminium-foil-50mmx50m/dp/52R8749)| 143650 | 1 | Shield sealing | **$39.80** | ☐ | ☐ |
| 24 | [Brass Screws (Knowles Voltronics 48-133)](https://www.digikey.ca/en/products/detail/knowles-voltronics/48-133/18680028) | 48-133 | 9 | Non-magnetic | **$36.63** | ☐ | ☐ |
| 25 | [Ground Cables (Green/Yellow 8 AWG Ground Wire)](https://falconerelectronics.com/product/ground-wire-9-5-x-green-yellow-8-ga-1-4-stud-to-1-4-stud-rohs/) | 1GY89.5OO1B | 5 | Scanner grounding | **$28.31** | ☐ | ☐ |
| 26 | [SMA Female to BNC Male Adapter (RF Solutions ADP-SMAF-BNCM)](https://www.digikey.ca/en/products/detail/rf-solutions/ADP-SMAF-BNCM/4271257) | ADP-SMAF-BNCM | 4 | RF adapter | **$33.64** | ☐ | ☐ |
| 27 | [BNC Cable (15 cm) - Amphenol RF 115101-19-06-00](https://www.digikey.ca/en/products/detail/amphenol-rf/115101-19-06-00/2505045) | 115101-19-06-00 | 4 | For RF Coil testing | **$70.80** | ☐ | ☐ |
| 28 |[Banana-to-Grabber Test Leads (36") - Pomona Electronics 3782-36-02](https://www.digikey.ca/en/products/detail/pomona-electronics/3782-36-02/736657) | 3782-36-02 | 6 | Test leads | **$201.72** | ☐ | ☐ |
| 29 | [Ethernet Cable (Eaton Tripp Lite N201P-006-BL)](https://www.digikey.ca/en/products/detail/eaton-tripp-lite/N201P-006-BL/15298306) | N201P-006-BL | 2 | Communication between Red Pitaya and Computer | **$34.62** | ☐ | ☐ |
| 30 | [Masking Tape (Scotch 3436)](https://www.amazon.ca/Scotch-Office-Masking-3436-3-4-inch/dp/B00347A8E4)| 3436-3 | 1 | General assembly | **$11.05** | ☐ | ☐ |

**Subtotal:** **$3,904.04 USD**

---

# 🔬 Required Laboratory Equipment

| No. | Equipment | Qty. | Total Cost | Available | On-site for Assembly |
|:---:|---|:---:|:---:|:---:|:---:|
| 1 | [Label Maker (Brother P-touch PTD210BK)](https://www.staples.ca/products/1671378-en-brother-p-touch-ptd210bk-easy-to-use-label-maker) | 1 | **$64.99** | ☐ | ☐ |
| 2 | [Drilling Machine (Milwaukee M18 Drill)](https://www.grainger.ca/en/product/p/MTL2606-20) | 1 | **$327.94** | ☐ | ☐ |
| 3 | [Soldering Station (Weller H-10799)](https://www.uline.ca/Product/Detail/H-10799/Anti-Static-Equipment/Soldering-Station) | 1 | **$258.00** | ☐ | ☐ |
| 4 | [NanoVNA (Vector Network Analyzer Alternative)](https://www.amazon.ca/Seesii-Analyzer-10KHz-1-5GHz-Measuring-Parameters/dp/B08132DJLS) | 1 | **$79.99** | ☐ | ☐ |
| 5 | [Function Generator (Digilent Analog Discovery 3)](https://www.tequipment.net/Digilent/Analog-Discovery-3/Function-Generator/)| 1 | **$379.00** | ☐ | ☐ |
| 6 | [Multimeter (Fluke FLUKE-15B+)](https://www.digikey.ca/en/products/detail/fluke-electronics/FLUKE-15B/24398487) | 1 | **$227.73** | ☐ | ☐ |
| 7 |[Oscilloscope (RIGOL DHO804 Digital Oscilloscope)](https://www.amazon.ca/Rigol-DHO804-Digital-Oscilloscope-Channels/dp/B0CGHQHQN7) | 1 | **$637.43** | ☐ | ☐ |
| 8 | [Vector Network Analyzer (VNA) - Siglent SVA1015X](https://siglentna.com/product/sva1015x/)| 1 | **$1,944.00** | ☐ | ☐ |
| 9 | [Cutter (DEWALT Impact Shears Attachment - DWASHRIR)](https://www.amazon.ca/DEWALT-DWASHRIR-Impact-Shears-Attachment/dp/B01BSAWORC) | 1 | **$70.00** | ☐ | ☐ |

**Subtotal:** **$2,045.08**

---

# 🖨️ Other Important Laboratory Equipment

| No. | Equipment | Part Number | Quantity | Notes | Total Cost | Available |
|:---:|---|---|:---:|---|:---:|:---:|
| 1 | [3D Printer (Bambu Lab P1S)](https://ca.store.bambulab.com/products/p1s?id=737896686575063052) | 737896686575063052 | 1 | For all printed toolkit parts | **$739.00** | ☐ |
| 2 | [PLA Basic Filament (Bambu Lab)](https://ca.store.bambulab.com/products/pla-basic-filament) | A00-G6-1.75-1000-SPL | 5 spools | 4 Green, 1 White | **$129.95** | ☐ |

**Subtotal:** **$868.95**

---

# ⚡ Other Important Electronics

| No. | Component | Quantity | Notes | Total Cost | Available |
|:---:|---|:---:|---|:---:|:---:|
| 1 | Pickup Coil | 1 | Constructed from BNC cables | — | ☐ |
| 2 | [Ceramic Capacitor (KEMET C1812C781KHGLCAUTO)](https://www.digikey.ca/en/products/detail/kemet/C1812C781KHGLCAUTO/15195497) | >50 | Fixed capacitors for RF tuning and matching | **$100.00** | ☐ |

---

# 💰 Estimated Total Cost

| Description | Cost |
|---|---:|
| **Grand Total Estimate** | **$10,516.12** |

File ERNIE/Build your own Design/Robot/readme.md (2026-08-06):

# Overview

<p style="text-align: justify;">
 
<p align="left"> The Kit includes the IMAGINE Field Mapping Robot. For detailed description on parts and assembly of the robot, <b> refer to </b>:
 
1. How-to-Video: [Video Link](https://github.com/CAMERA-MRI/IMAGINE/tree/main/ERNIE/Build%20your%20own%20Design/Robot/Robot%20introductory%20video)
2. Parts and Assembly Guide Repository:   [Repo](https://github.com/SipanHovsep/Field_mapper_robot)
3. [🤖 Robot Field Mapping Software](https://github.com/CAMERA-MRI/IMAGINE/tree/main/ERNIE/Build%20your%20own%20Design/Robot/Field%20Mapping%20Software)
 
<p align="center"> robot t </p>
</p>
</p>

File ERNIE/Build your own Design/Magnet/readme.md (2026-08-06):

# 🧲 Main magnet.

## Overview.

<p style="text-align: justify;">
This section includes the <b>.stl </b> files that can be 3D printed out to then assemble the ERNIE 1&2 scanners. The scanner is made up of   <b>7 rings </b> and their corresponding lids. We also includes the steps taked to assemble the magnet.
The best rings are <b>Ring_321</b> which is placed at the center of the Halbach array. <b>Ring_288</b> then follows on both sides of the center ring. The next ring is <b>Ring_251</b> and finally <b>Ring_42</b>.

</p>
  
## 🛠️ Magnet assembly procedure

The magnet assembly steps are explained in detail here:  
 
 [How to assemble the magnet](https://github.com/CAMERA-MRI/IMAGINE/blob/main/ERNIE/Build%20your%20own%20Design/Magnet/Instructions/How%20to%20assemble%20the%20magnet.pdf)

<p align="center">magnet assembly procedure</p>
</p>

<p style="text-align: justify;">
The sequence of steps for the scanner magnet assembly is summarized, from determining magnet polarities <b> (A) </b>, to installation of magnets in ring slots and alignment check for each ring using a compass <b> (B). Each ring is then covered with a lid  <b> (C) </b>, screwed down <b> (D) </b>, and all 7 rings are assembled with brass rods, supported by spacers <b> (E) </b>, to make a complete array as designed <b> (F)</b>.
</p>
  ChatGPT Image Jul 30, 2026, 11_29_02 AM

</p>

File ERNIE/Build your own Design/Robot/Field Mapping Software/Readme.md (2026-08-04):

## Overview
  [Arduino script ino](https://github.com/CAMERA-MRI/IMAGINE/blob/main/ERNIE/Build%20your%20own%20Design/Robot/Field%20Mapping%20Software/Arduino_script.ino) is the software for running the 3D field mapping robot to map the ERNIE magnet. The script is based on [Arduino script ino_original](https://github.com/SipanHovsep/Field_mapper_robot/blob/main/scripts/Arduino_script.ino)

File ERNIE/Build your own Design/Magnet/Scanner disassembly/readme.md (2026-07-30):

## Overview

<p style="text-align: justify;">
This section includes the guidelines to follow during disassembly of the ERNIE magnet and robot, and a disassembly tray where magnets are placed after tray disassembly. We also included the dissassembly tray <b>.stl</b> file and the disassembly tray cover.
Disassembly must be done in a very careful way, to ensure that the magnets do not bang onto each other and crack.
Magnet ousters are used in the process. First, a cutter is used to sharpen the ends of the ousters so they can push the pagnets out of the rings with ease.
 
<p style="text-align: justify;">
<b>Note : </b> Never use a screw driver of any sharp metallic tool to push out magnets from the scanner rings because these scratch the surfaces of the neodymium magnets.
As magnets are pushed out of their slots in the rings, the permanent mark ( arrow ) might be erased. Permanent markers are then used to re-fraw the arrow. 
To ensure the arrows are re-drawn in the right direction, reference magnets are used to check those magnets.
When the magnets are pushed out of the ring, they are pushed into the magnet slots in the magnet disassembly tray.
</p>

</p>

<p style="text-align: justify;">
The figure below shows a magnet ouster, <b>Ring_42</b> with magnets in its magnet slots after disassembly and a disassembly tray with the magnets facing in different directions. </p>

### Figure showing Ring_42 after scanner disassembly, and disassembly tray with N48 magnets

 <p align="center">
disassembly tray </p>

<p style="text-align: justify;">
The disassembly tray was designed with rows of magnet slots facing in alternating directions to cancel out the magnetic field. This keeps the magnetic field <b>weak</b> as a result of the magnets placed in the disassembly tray weak. The magnets can then be transported easily.
</p>

</p>

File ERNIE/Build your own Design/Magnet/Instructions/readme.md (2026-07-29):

# Instructions
## Overview
<p style="text-align: justify;">
This section includes the animation, ERNIE scanner optimisation information, steps on how to assemble the magnet, and steps on how to design ERNIE rings using Autodesk inventor. It also includes the magnet and robot assembly checklists.
 </p>
 
## Magnet checklist  
# ✅ ERNIE Build Checklists

Use these checklists before and after each workshop to ensure all components are available, assembled, disassembled, and returned to their storage cases.

# 🧲 Magnet Assembly Checklist

## 📦 Carrying Case

| No. | Item | Qty | 📦 Available |
|:---:|---|:---:|:---:|
| 1 | Yellow Carrying Case | 1 | ☐ Yes ☐ No |

---

## 🧲 Magnet Parts

| No. | Part | Quantity | 📦 Available | 🔧 Added to Assembly | 🔄 Disassembled |
|:---:|---|:---:|:---:|:---:|:---:|
| 1 | Ring 42 | 2 | ☐ Yes ☐ No | ☐ | ☐ |
| 2 | Ring 251 | 2 | ☐ Yes ☐ No | ☐ | ☐ |
| 3 | Ring 288 | 2 | ☐ Yes ☐ No | ☐ | ☐ |
| 4 | Ring 321 | 1 | ☐ Yes ☐ No | ☐ | ☐ |
| 5 | Lids for Ring 42 | 2 | ☐ Yes ☐ No | ☐ | ☐ |
| 6 | Lids for Ring 251 | 2 | ☐ Yes ☐ No | ☐ | ☐ |
| 7 | Lids for Ring 288 | 2 | ☐ Yes ☐ No | ☐ | ☐ |
| 8 | Lid for Ring 321 | 1 | ☐ Yes ☐ No | ☐ | ☐ |
| 9 | 180 mm Brass Rods | 8 | ☐ Yes ☐ No | ☐ | ☐ |
| 10 | Ring Spacers | 48 | ☐ Yes ☐ No | ☐ | ☐ |
| 11 | Nylon Nuts | 8 | ☐ Yes ☐ No | ☐ | ☐ |
| 12 | Nylon Screws | 54 | ☐ Yes ☐ No | ☐ | ☐ |
| 13 | Nylon Dome Nuts | 8 | ☐ Yes ☐ No | ☐ | ☐ |
| 14 | Nylon Washers | 16 | ☐ Yes ☐ No | ☐ | ☐ |
| 15 | Neodymium Magnets | 98 | ☐ Yes ☐ No | ☐ | ☐ |

---

## 🛠️ Magnet Assembly Tools

| No. | Tool | Quantity | 📦 Available | 📥 Returned to Box |
|:---:|---|:---:|:---:|:---:|
| 1 | Screwdrivers | 4 | ☐ Yes ☐ No | ☐ |
| 2 | Spanners | 4 | ☐ Yes ☐ No | ☐ |
| 3 | Compass | 2 | ☐ Yes ☐ No | ☐ |
| 4 | Permanent Markers | 4 | ☐ Yes ☐ No | ☐ |
| 5 | Reference Magnets | 4 | ☐ Yes ☐ No | ☐ |
| 6 | Vernier Caliper | 1 | ☐ Yes ☐ No | ☐ |

---

## 🔄 Magnet Disassembly Tools

| No. | Tool | Quantity | 📦 Available | 📥 Returned to Box |
|:---:|---|:---:|:---:|:---:|
| 1 | Magnet Ousters | 6 | ☐ Yes ☐ No | ☐ |
| 2 | Disassembly Tray | 1 | ☐ Yes ☐ No | ☐ |
| 3 | Tape | 1 | ☐ Yes ☐ No | ☐ |
| 4 | Permanent Markers | 3 | ☐ Yes ☐ No | ☐ |
| 5 | Screwdrivers | 2 | ☐ Yes ☐ No | ☐ |
| 6 | Brass Screws | 6 | ☐ Yes ☐ No | ☐ |

---

# 🤖 Robot Assembly Checklist

## 🤖 Robot Parts

| No. | Part | Quantity | 📦 Available | 🔧 Added to Assembly | 🔄 Disassembled |
|:---:|---|:---:|:---:|:---:|:---:|
| 1 | Magnet Rails | 3 | ☐ Yes ☐ No | ☐ | ☐ |
| 2 | Motor Drivers | 3 | ☐ Yes ☐ No | ☐ | ☐ |
| 3 | Motor Driver Casing | 1 | ☐ Yes ☐ No | ☐ | ☐ |
| 4 | Arduino Uno | 1 | ☐ Yes ☐ No | ☐ | ☐ |
| 5 | Power Supply | 1 | ☐ Yes ☐ No | ☐ | ☐ |
| 6 | 3D Printed Bases | 2 | ☐ Yes ☐ No | ☐ | ☐ |
| 7 | Gauss Meter | 1 | ☐ Yes ☐ No | ☐ | ☐ |
| 8 | Gauss Meter Probe Holder | 1 | ☐ Yes ☐ No | ☐ | ☐ |
| 9 | Gauss Meter Probe Calibrator | 1 | ☐ Yes ☐ No | ☐ | ☐ |
| 10 | Gauss Meter Casing | 1 | ☐ Yes ☐ No | ☐ | ☐ |
| 11 | Gauss Meter Probe | 1 | ☐ Yes ☐ No | ☐ | ☐ |
| 12 | Screws | 8 | ☐ Yes ☐ No | ☐ | ☐ |
| 13 | Computer | 1 | ☐ Yes ☐ No | ☐ | ☐ |
| 14 | Connecting Wires | 25 | ☐ Yes ☐ No | ☐ | ☐ |
| 15 | USB-A to USB-C Cable | 1 | ☐ Yes ☐ No | ☐ | ☐ |
| 16 | USB-A to Micro-USB Cable | 1 | ☐ Yes ☐ No | ☐ | ☐ |

---

## 🛠️ Robot Tools

| No. | Tool | Quantity | 📦 Available | 📥 Returned to Box |
|:---:|---|:---:|:---:|:---:|
| 1 | Screwdrivers | 4 | ☐ Yes ☐ No | ☐ |
| 2 | Tape | 2 | ☐ Yes ☐ No | ☐ |
| 3 | Ruler | 2 | ☐ Yes ☐ No | ☐ |
| 4 | Allen Keys | 2 | ☐ Yes ☐ No | ☐ |
| 5 | Pliers | 1 | ☐ Yes ☐ No | ☐ |

## ✅ Final Verification

Before storing the toolkit:

- [ ] All parts accounted for
- [ ] Magnet fully disassembled
- [ ] Robot fully disassembled
- [ ] Tools returned to their designated compartments
- [ ] Carrying case securely closed
- [ ] Toolkit ready for transport

 </p>

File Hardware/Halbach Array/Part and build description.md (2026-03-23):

## Part description and how to arrange them

### Hardware Components

| Name | Description |
|---|---|
| **Brass_Rod_M4.ipt** | 4mm Threaded brass rod 262 mm long. 8 of these rods are used to fasten the rings together, structurally connect them and provide the means to create the necessary spacing between the rings. |
| **M3x8.ipt** | A 3mm diameter 8mm long screw. These are used to fasten the lids to the ring housings. A total of 125 screws are required to fasten all the lids. |
| **M4 Dome nut.ipt** | These nuts act as the fasteners for the brass rod ends which protrude out on either end of the assembled magnet rings. The dome nuts are fastened on the back end of Ring_10_Back and the front of Ring_10. A total of 16 half dome nuts is required to fasten both ends. |
| **M4_Nylon_Washer.ipt** | Washers that are used anytime when a fastener (nut) is used to fasten against a ring housing. The washers should be placed between the ring housing and the fastener. |
| **M4x3.2mm Hex Nut.ipt** | M4 nuts used to hold the ring housings in place along the brass rods. These nuts are used to determine the spacing between rings on the brass rod and ensure they remain in place at those positions. The nuts are placed on either side of the ring housing (unless they are the rings on the ends (Ring_10). A total of 160 hex nuts are used. |

---

### Lids

| Name | Description |
|---|---|
| **Lid_Loose.ipt** | Lid used specifically for Rings 842, 945 and 1050. This lid has 13 3.5mm holes to accommodate the M3 screws. These lids need to be made to prevent magnets from falling out of the ring housings. 5 of these lids need to be made for the following ring housings: 1 x Ring 842, 2x Ring 946 and 2x Ring 1050 |
| **Lid_tight.ipt** | Lid used specifically for Rings 0, 1 and 10. This lid has 10 3.5mm holes to accommodate the M3 screws. 6 of these lids need to be made to prevent magnets from falling out of the ring housings. 6 of these rings need to be made for the following ring housings: 2x Ring 0, 2x Ring 1 and 2x Ring 10. |

---

### Ring Housings

| Name | Description |
|---|---|
| **Ring_0.ipt** | Part file for ring housing Ring_0. Designed to hold 12x12x12mm magnets in place at a designed radius and orientation. Follows Halbach array structure. The ring contains 10 4.2mm holes to give space for heat inserts to be placed so that M3x8 screws can be fastened into the 3D print. |
| **Ring_1.ipt** | Part file for ring housing Ring_1. Designed to hold 12x12x12mm magnets in place at a designed radius and orientation. Follows Halbach array structure. The ring contains 10 4.2mm holes to give space for heat inserts to be placed so that M3x8 screws can be fastened into the 3D print. |
| **Ring_10.ipt** | Part file for ring housing Ring_10. Designed to hold 12x12x12mm magnets in place at a designed radius and orientation. Follows Halbach array structure. Each ring contains 10 4.2mm holes to give space for heat inserts to be placed so that M3x8 screws can be fastened into the 3D print. This Ring_10 is positioned at the “front” of the assembly and has 4.2mm holes on its front side to allow heat inserts to be placed, so that the shim trays can be fastened to the ring with M3x* screws. |
| **Ring_10_back.ipt** | Part file for ring housing Ring_10_back. Designed to hold 12x12x12mm magnets in place at a designed radius and orientation. Follows Halbach array structure. Each ring contains 10 4.2mm holes to give space for heat inserts to be placed so that M3x8 screws can be fastened into the 3D print. This Ring_10_back is positioned at the “back” of the assembly and has 4.2mm holes on its back side to allow heat inserts to be placed, so that the shim trays can be fastened to the ring with M3x8 screws. |
| **Ring_842.ipt** | Part file for ring housing Ring_842. Designed to hold 12x12x12mm magnets in place at a designed radius and orientation. Follows Halbach array structure. The ring contains 13 4.2mm holes to give space for heat inserts to be placed so that M3x8 screws can be fastened into the 3D print. This ring is the central ring of the assembly. |
| **Ring_945.ipt** | Part file for ring housing Ring_945. Designed to hold 12x12x12mm magnets in place at a designed radius and orientation. Follows Halbach array structure. The ring contains 13 4.2mm holes to give space for heat inserts to be placed so that M3x8 screws can be fastened into the 3D print. |
| **Ring_1050.ipt** | Part file for ring housing Ring_1050. Designed to hold 12x12x12mm magnets in place at a designed radius and orientation. Follows Halbach array structure. The ring contains 13 4.2mm holes to give space for heat inserts to be placed so that M3x8 screws can be fastened into the 3D print. |

---

### Ring Subassemblies

| Name | Description |
|---|---|
| **Ring_0_Sub.iam** | Subassembly for Ring_0. This includes the Ring housing Ring_0, Lid_tight and the 10 M3x8 screws used to fasten the lid to the housing. |
| **Ring_1_Sub.iam** | Subassembly for Ring_1. This includes the Ring housing Ring_1, Lid_tight and the 10 M3x8 screws used to fasten the lid to the housing. |
| **Ring_10_Sub.iam** | Subassembly for Ring_10. This includes the Ring housing Ring_10_back, Lid_tight and the 10 M3x8 screws used to fasten the lid to the housing. This subassembly is placed at the front of the assembly. |
| **Ring_10_Back_Sub.iam** | Subassembly for Ring_10_back. This includes the Ring housing Ring_10_back, Lid_tight and the 10 M3x8 screws used to fasten the lid to the housing. This subassmble is placed at the back of the assembly. |
| **Ring_842_Sub.iam** | Subassembly for Ring_842. This includes the Ring housing Ring_842, Lid_Loose and the 13 M3x8 screws used to fasten the lid to the housing. |
| **Ring_945_Sub.iam** | Subassembly for Ring_945. This includes the Ring housing Ring_945, Lid_Loose and the 13 M3x8 screws used to fasten the lid to the housing. |
| **Ring_1050_Sub.iam** | Subassembly for Ring_1050. This includes the Ring housing Ring_1050, Lid_Loose and the 13 M3x8 screws used to fasten the lid to the housing. |

---

### Full Assembly

| Name | Description |
|---|---|
| **Rat_Scanner_120_Ass.iam** | Full assembly of all components to construct the 120mm bore diameter rat scanner magnet assembly. This full assembly makes use of Ring subassemblies. |

---

### Shimming Components

| Name | Description |
|---|---|
| **Shim_Tray.ipt** | Part file for the shim tray. The shim tray is to be slotted into any of the 8 slots in the magnet assembly. There are 8 slots on the front side of the assembly and 8 on the back. The tray is designed to house cartridges that contain the shim magnets. This tray has not been tested yet. |

---
### Notes:

The assembly must be constructed utilising a mirrored fashion, with Ring 842 being the central ring and the others stacked in their precise positions on either side, such as in the figure below:
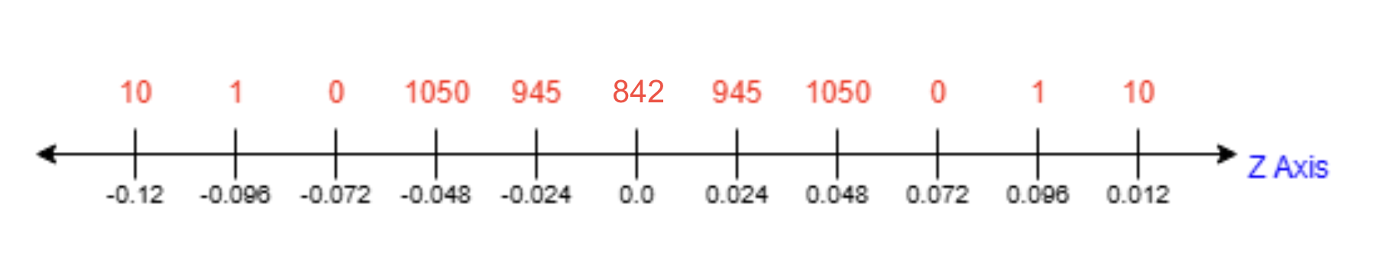
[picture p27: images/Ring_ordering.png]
Ring order.
<br/><br/>

Although the rings positions are mirrored, the direction they face is not. All rings must be stacked and assembled with the Ring housing side that contains the magnets facing in the same direction. Therefore, on the ends of the assembly, the “front” side of the assembly will be the magnet facing side of Ring_10.ipt and the end of the assembly will be the back facing side of Ring_10_back.ipt. Remember when positioning the rings that the position is based on the center of the 12mm magnets within the ring, and not the centre of the ring housing itself (which has a width of 14mm).

---
### Additional information: File types

🔹 **.ipt – Part file (Autodesk Inventor)**

- Used by: Autodesk Inventor
-	Purpose: Single 3D part
-	Contains:
	-	Geometry of one component
	-	Features (extrusions, sketches, etc.)
	-	Material properties

🔹 **.iam – Assembly file (Autodesk Inventor)**
 
-	Used by: Autodesk Inventor
-	Purpose: Assembly of multiple parts
-	Contains:
	 -	References to .ipt files
	 - Constraints (how parts fit together)
	 -	Positioning and motion relationships

🔹 **.stp / .step – Neutral exchange format**

-	Full name: STEP (Standard for the Exchange of Product Data)
-	Used by: Almost all CAD software (e.g., SolidWorks, Fusion 360, etc.)
-	Purpose: Interoperability between CAD programs
-	Contains:
	-	3D geometry (solids/surfaces)
	-	Sometimes basic assembly structure
	-	Does NOT preserve:
	-	Parametric history (features, sketches)
	-	Full constraints

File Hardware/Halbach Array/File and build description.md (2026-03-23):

**Brass_Rod_M4.ipt:**

4mm Threaded brass rod 262 mm long. 8 of these rods are used to fasten the rings together, structurally connect them and provide the means to create the necessary spacing between the rings.

**Lid_Loose.ipt:**

Lid used specifically for Rings 842, 945 and 1050. This lid has 13 3.5mm holes to accommodate the M3 screws.  These lids need to be made to prevent magnets from falling out of the ring housings. 5 of these lids need to be made for the following ring housings:  1 x Ring 842, 2x Ring 946 and 2x Ring 1050

**Lid_tight.ipt:**

Lid used specifically for Rings 0, 1 and 10. This lid has 10 3.5mm holes to accommodate the M3 screws. 6 of these lids need to be made to prevent magnets from falling out of the ring housings. 6 of these rings need to be made for the following ring housings: 2x Ring 0, 2x Ring 1 and 2x Ring 10.

**M3x8.ipt:**

A 3mm diameter 8mm long screw. These are used to fasten the lids to the ring housings. A total of 125 screws are required to fasten all the lids.

**M4 Dome nut.ipt:**

These nuts act as the fasteners for the brass rod ends which protrude out on either end of the assembled magnet rings. The dome nuts are fastened on the back end of Ring_10_Back and the front of Ring_10. A total of 16 half dome nuts is required to fasten both ends.

**M4_Nylon_Washer.ipt:**

Washers that are used anytime when a fastener (nut) is used to fasten against a ring housing. The washers should be placed between the ring housing and the fastener.

**M4x3.2mm Hex Nut.ipt:**

M4 nuts used to hold the ring housings in place along the brass rods. These nuts are used to determine the spacing between rings on the brass rod and ensure they remain in place at those positions. The nuts are placed on either side of the ring housing (unless they are the rings on the ends (Ring_10). A total of 160 hex nuts are used.

**Rat_Scanner_120_Ass.iam:**

Full assembly of all components to construct the 120mm bore diameter rat scanner magnet assembly. This full assembly makes use of Ring subassemblies. 

**Ring_0_Sub.iam:**

Subassembly for Ring_0. This includes the Ring housing Ring_0, Lid_tight and the 10 M3x8 screws used to fasten the lid to the housing.
 

**Ring_0.ipt:**

Part file for ring housing Ring_0. Designed to hold 12x12x12mm magnets in place at a designed radius and orientation. Follows Halbach array structure. The ring contains 10 4.2mm holes to give space for heat inserts to be placed so that M3x8 screws can be fastened into the 3D print.

**Ring_1_Sub.iam:**

Subassembly for Ring_1. This includes the Ring housing Ring_1, Lid_tight and the 10 M3x8 screws used to fasten the lid to the housing.

**Ring_1.ipt:**

Part file for ring housing Ring_1. Designed to hold 12x12x12mm magnets in place at a designed radius and orientation. Follows Halbach array structure. The ring contains 10 4.2mm holes to give space for heat inserts to be placed so that M3x8 screws can be fastened into the 3D print.

**Ring_10_Back_Sub.iam:**

Subassembly for Ring_10_back. This includes the Ring housing Ring_10_back, Lid_tight and the 10 M3x8 screws used to fasten the lid to the housing. This subassmble is placed at the back of the assembly.

**Ring_10_back.ipt:**

Part file for ring housing Ring_10_back. Designed to hold 12x12x12mm magnets in place at a designed radius and orientation. Follows Halbach array structure. Each ring contains 10 4.2mm holes to give space for heat inserts to be placed so that M3x8 screws can be fastened into the 3D print. This Ring_10_back is positioned at the “back” of the assembly and has 4.2mm holes on its back side to allow heat inserts to be placed, so that the shim trays can be fastened to the ring with M3x8 screws.

**Ring_10_Sub.iam:**

Subassembly for Ring_10. This includes the Ring housing Ring_10_back, Lid_tight and the 10 M3x8 screws used to fasten the lid to the housing. This subassembly is placed at the front of the assembly.

**Ring_10.ipt:**

Part file for ring housing Ring_10. Designed to hold 12x12x12mm magnets in place at a designed radius and orientation. Follows Halbach array structure. Each ring contains 10 4.2mm holes to give space for heat inserts to be placed so that M3x8 screws can be fastened into the 3D print. This Ring_10 is positioned at the “front” of the assembly and has 4.2mm holes on its front side to allow heat inserts to be placed, so that the shim trays can be fastened to the ring with M3x* screws.

**Ring_842_Sub.iam:**

Subassembly for Ring_842. This includes the Ring housing Ring_842, Lid_Loose and the 13 M3x8 screws used to fasten the lid to the housing.
 
 
**Ring_842.ipt:**

Part file for ring housing Ring_842. Designed to hold 12x12x12mm magnets in place at a designed radius and orientation. Follows Halbach array structure. The ring contains 13 4.2mm holes to give space for heat inserts to be placed so that M3x8 screws can be fastened into the 3D print. This ring is the central ring of the assembly.

**Ring_945_Sub.iam:**

Subassembly for Ring_945. This includes the Ring housing Ring_945, Lid_Loose and the 13 M3x8 screws used to fasten the lid to the housing.

**Ring_945.ipt:**

Part file for ring housing Ring_945. Designed to hold 12x12x12mm magnets in place at a designed radius and orientation. Follows Halbach array structure. The ring contains 13 4.2mm holes to give space for heat inserts to be placed so that M3x8 screws can be fastened into the 3D print.

**Ring_1050_Sub.iam:**

Subassembly for Ring_1050. This includes the Ring housing Ring_1050, Lid_Loose and the 13 M3x8 screws used to fasten the lid to the housing.

**Ring_1050.ipt:**

Part file for ring housing Ring_1050. Designed to hold 12x12x12mm magnets in place at a designed radius and orientation. Follows Halbach array structure. The ring contains 13 4.2mm holes to give space for heat inserts to be placed so that M3x8 screws can be fastened into the 3D print.

**Shim_Tray.ipt:**

Part file for the shim tray. The shim tray is to be slotted into any of the 8 slots in the magnet assembly. There are 8 slots on the front side of the assembly and 8 on the back. The tray is designed to house cartridges that contain the shim magnets. This tray has not been tested yet.

**Notes:**

The assembly must be constructed utilising a mirrored fashion, with Ring 842 being the central ring and the others stacked in their precise positions on either side, such as in the figure below:
<br/><br/><p align="center">Ring order.</p>

Although the rings positions are mirrored, the direction they face is not. All rings must be stacked and assembled with the Ring housing side that contains the magnets facing in the same direction. Therefore, on the ends of the assembly, the “front” side of the assembly will be the magnet facing side of Ring_10.ipt and the end of the assembly will be the back facing side of Ring_10_back.ipt. Remember when positioning the rings that the position is based on the center of the 12mm magnets within the ring, and not the centre of the ring housing itself (which has a width of 14mm).

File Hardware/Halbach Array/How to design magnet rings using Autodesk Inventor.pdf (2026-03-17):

HOW TO MAKE THE 3D DESIGN USING AUTODESK

INVENTOR

Thursday, May 22, 2025 9:43 AM
Step 1
Install the software. During this step, one could install either Autodesk Inventor/ Solid Works/ AutoCAD for CAD design. https://www.autodesk.com/education/edu-software/overview#INVPROSA (https://www.autodesk.com/education/edu-software/overview#INVPROSA)
Select the student version in order to get a cheaper version.
Step 2.
Navigate to the File of results and Identify which ring you will design first. For example, the first ring is the center ring, 842. The inner bore is 120mm, Outer bore is 190mm. Then the outer-most circle where the shim trays are added is 240mm.
Step 3.
After looking at design parameters, open Autodesk Inventor. Select File> New> Templates> Metric> (Standard)mm> Create. This sets the dimensions from the default ( Inches to mm).
The display of the background is usually dark so one can also change this to sky by selecting ( File> Options> Colors> Sky.
Then select apply to apply these changes.
Step 4
When the new part is created, all the planes are invisible. To make them visible, select Origin> Right click Planes> Visible. Do this for the YZ, XZ and XY planes.
Right click on the XY plane and make it perpendicular ( or navigate to the Sketch menu> select the perpendicular sign).
Step 5: Draw circles
To draw the inner bore, navigate to the Sketch > Center circle. Draw the circle while starting at the center. Set the diameter to 120mm. Draw a second circle for the outer bore of the ring and set its diameter as 190mm. Draw a third circle ( for the shim trays ) and set its diameter to 240mm.
For this case, Inner bore diameter = 80mm, Outer bore diameter = 160mm and the outermost bore diameter = 190mm.

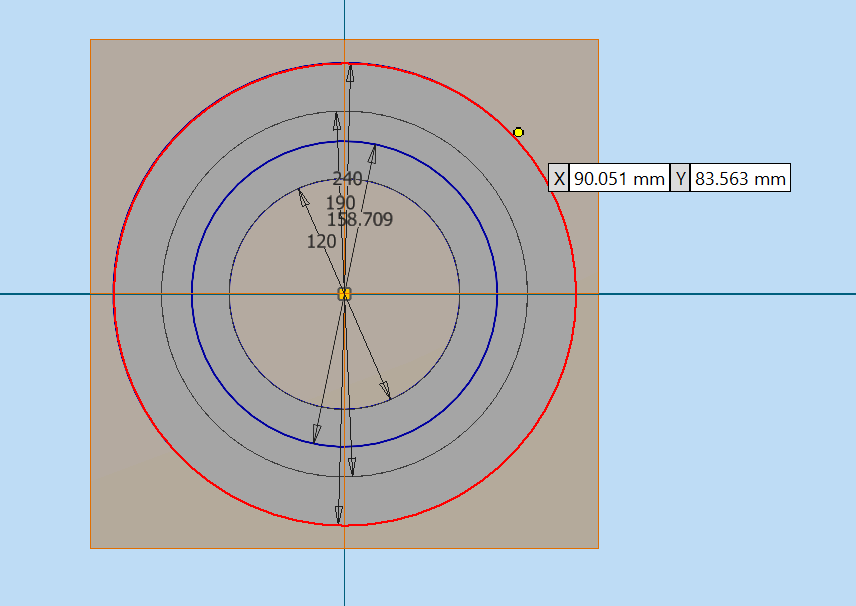
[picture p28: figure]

Step 6: Extrude the circles
After drawing the circles, finish sketch. First extrude the inner circle by 14mm. Finish the sketch. Then right click on the sketch and select visible. Then extrude the second face by 12mm.
Select the inner section and extrude it by 14mm. Select the outer region and extrude it by 12mm.

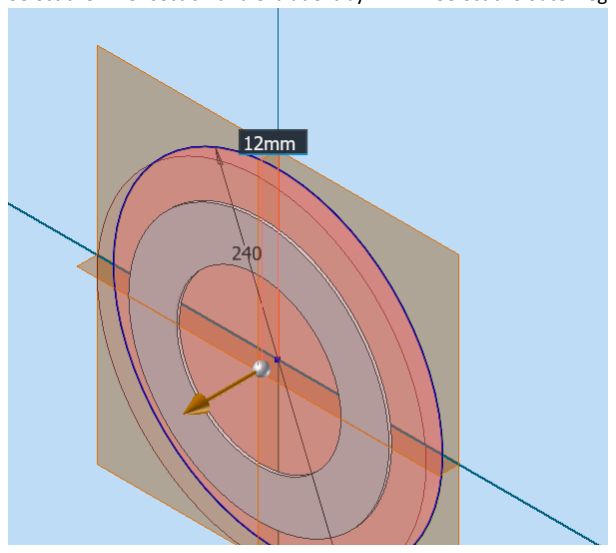
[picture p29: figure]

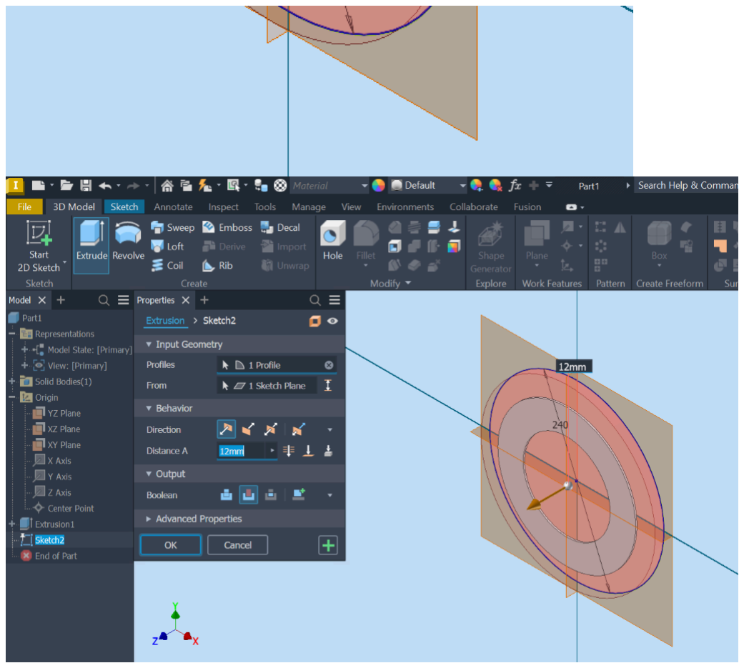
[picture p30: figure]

Step 7: Drawing the magnet Band
From the field results, band-radius is shown. For example, the 842 middle ring as a band radius of 78.702mm. Draw a circle. Set the entire diameter as 157.404mm. Press enter. That is the band where the magnets will be.
Step 8: Create Magnet Block
Select the Sketch 5, where the band-radius line is and select edit sketch to draw the magnet block. Select the two side rectangle and draw at the horizontal line that crosses the radius band circle at 180 degrees.

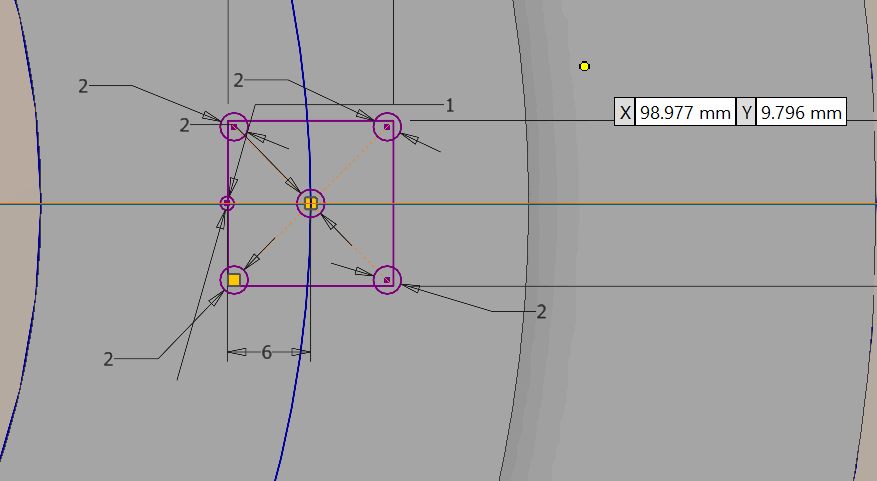
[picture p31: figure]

The dimensions of the magnet are 11.8mmX 11.8mmX 11.8mm after measuring. So dimension the rectangle as 11.8mm. So it forms a square.
Draw a little dot on the side of the square facing the midpoint of the entire ring. This will give the direction in which the magnets will rotate. Dimension it such that the distance between the centre of the dot and center of the square is 6mm. Set the diameter of the dot to 1mm.
Draw other small circles at the four corners of the square. Set their diameters to 2mm each. There are such that the magnet can be fit into the hole with ease.
Draw another circle at the center of the square and set its radius to 2mm. This is so as to ease the process of removing a magnet if necessary.
To create a magnet block navigate to Folder Model> Block> Create Block/ Sketch>Edit Sketch Select all the lines, circles and points associated with the newly created block.

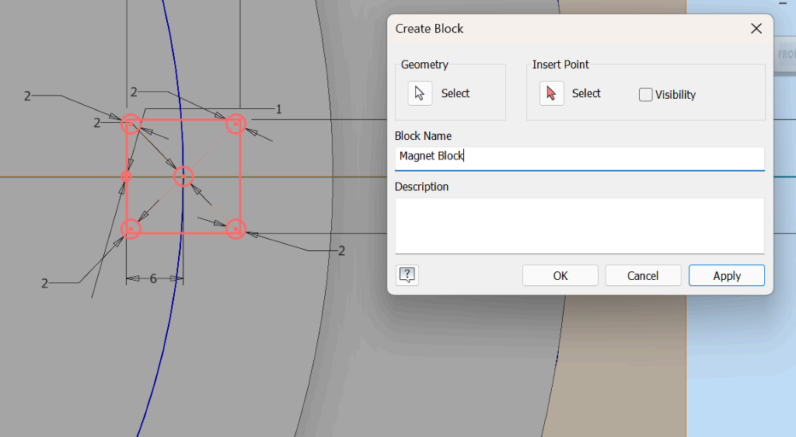
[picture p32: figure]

Select insert point and choose the center of the block. This selects the point at which the block will be inserted at each point of the band-radius. Input a block Name as Magnet Block . Click on apply to create it. All the center points of circles and rectangle should change to color white.
Click the green tick to finish.
You can hide the other sketches to create more focus on the magnet block.
Then finish the sketch and hide it.

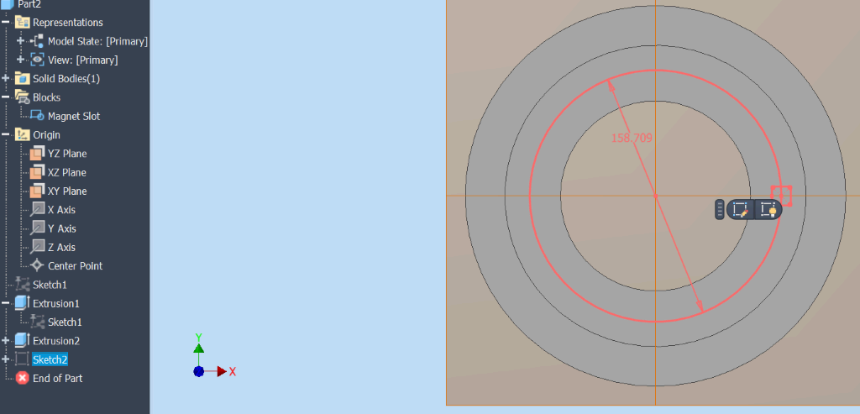
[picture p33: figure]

Still within the sketch mode, draw a new radii band circle and make its diameter 157.404. Right click on the radii band circle, select edit block. Then right click on the magnet block, select place block and place it at the first point.
Place a magnet block onto it.
If you try moving the block, it will move entirely. In order to fix it, draw a line from the center of the ring to its corresponding point on the radii band circle. Now place the magnet block at the point where this horizontal line meets the band. The center of the block should turn green.
Try to move the block around and it should rotate about the point at 360 degrees
From the results file, identify the number of magnets in the selected band for that specific ring. For example, the center ring 842 has 20 magnets.
Here, a pattern is made of the magnet blocks. Select Edit Sketch ( the radii band circle with the magnet block),Choose the circular pattern option then for axis, select the center of the ring and for geometry select the horizontal line from the center of ring to center of block. [select the horizontal line from the center of the ring to the center of the magnet block. Select the ring center as the axis and make 20 patterns]. Select OK.
Select the magnet block from the menu and place it at every end of the line. Make sure the center point of the magnet ( Insert point) turns green when the magnet block is placed at every point.

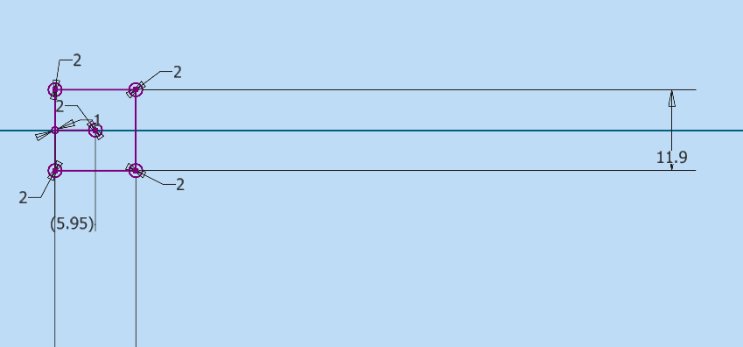
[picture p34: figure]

Then, still in the sketch mode, select edit block.
Draw a line from the center of the block to the center of the small circle placed 6mm away from the center of the magnet slot.
Step 9 : Dimension the angels between the magnets.

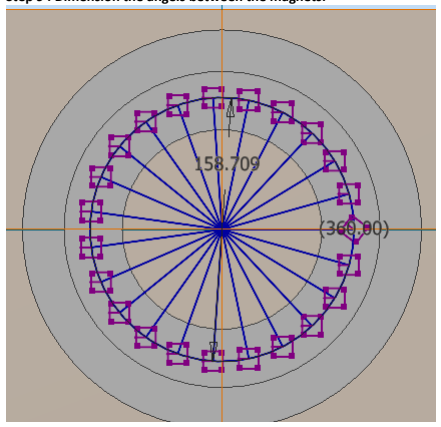
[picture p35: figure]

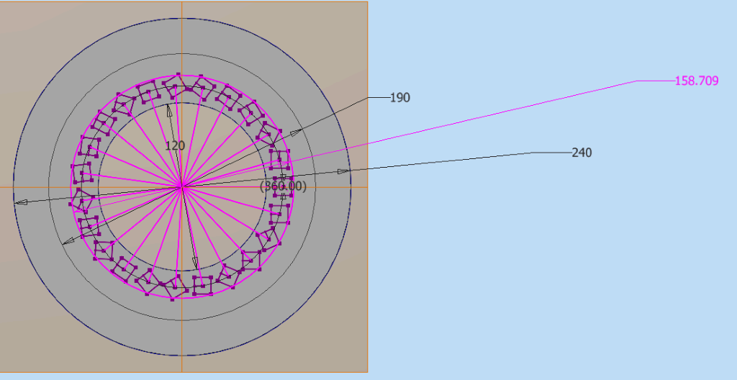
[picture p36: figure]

In preparation for dimensioning the magnet slots, tilt them so that they do not auto-connect to anything. This is done to make sure the dimensions are angular and not linear.

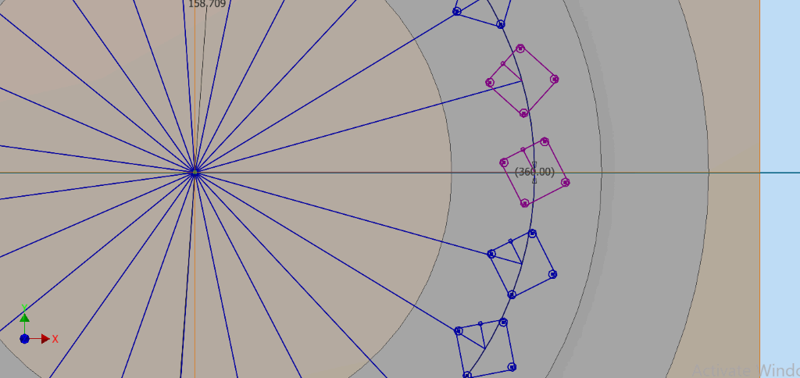
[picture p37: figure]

Step 10: DIMENSIONS FOR THE MAGNET SLOTS
Note: To simplify the dimensioning process, make sure that all the magnet slots are purple in color hence flexible. That way, one can change their dimensions and angle of orientation. If the magnet slots are blue, then they are already fixed.
Here use the formula for halbach array which is: 360(2)/n. N is the number of magnets.
For example, for the 120mm inner bore diameter ring, the first ring to be designed is the middle ring
842. From the results obtained from the algorithm, the ring has 20 magnets .
360(2)/20= 36.
This means their is an angular difference of 36 degrees for each slot.
However, this value is a negative because the magnet slots are rotated in the anti-clockwise direction
After setting the specific angular dimension for a slot, it attains a fixed orientation. The fixed slots are blue while the flexible ones are purple.

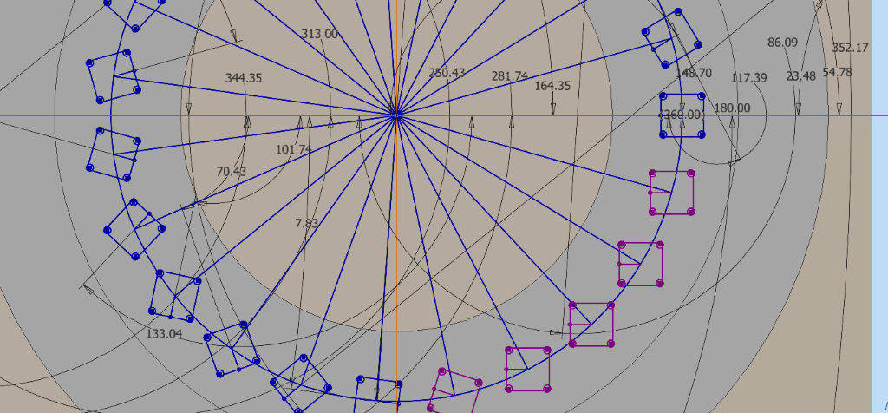
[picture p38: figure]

After putting all the angular dimensions, all the rings should appear blue.
Next, navigate to Manage> Parameters. This enables one to look through all the angles and ensure that they are the right ones.
If there are any errors, correct them. Then, save.

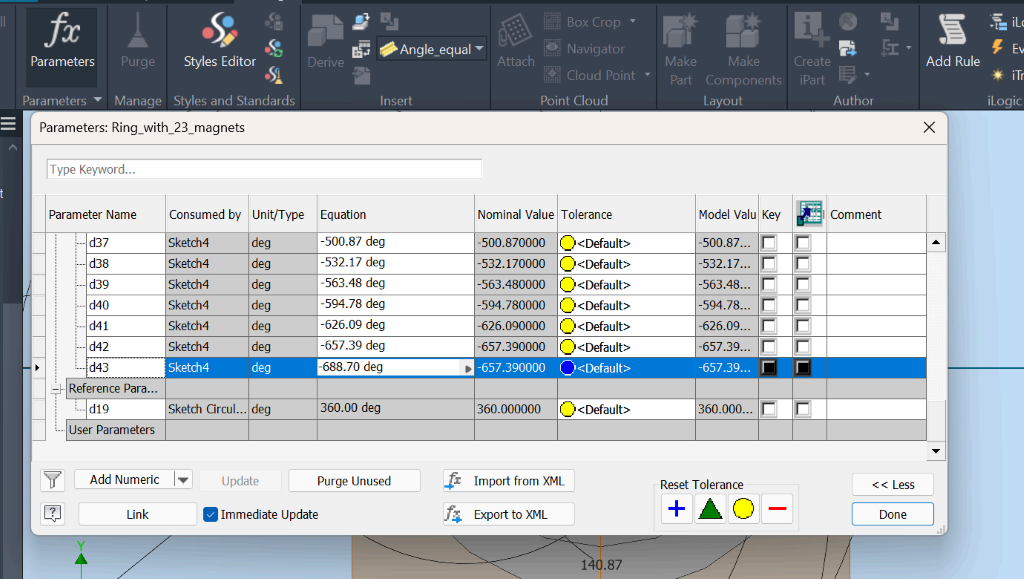
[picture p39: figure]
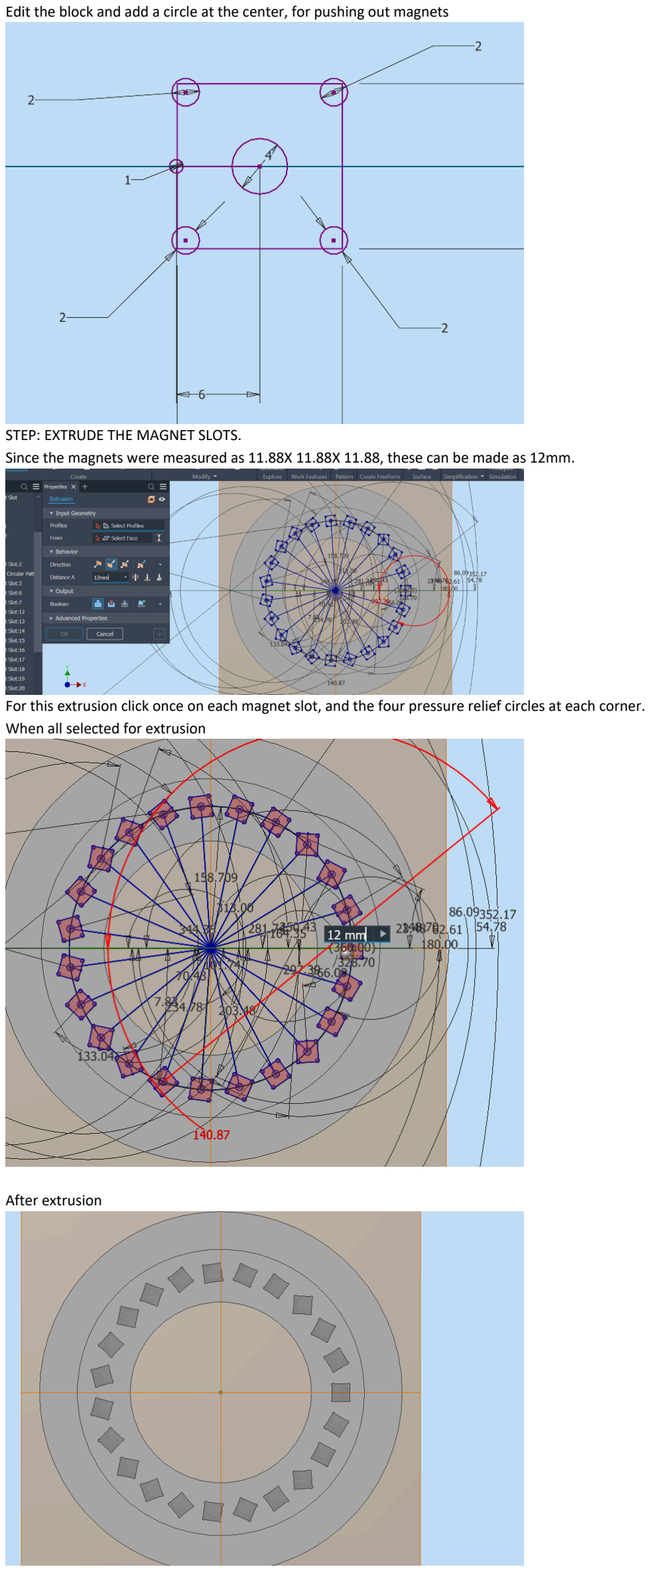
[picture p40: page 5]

Edit the block and add a circle at the center, for pushing out magnets

STEP: EXTRUDE THE MAGNET SLOTS.
Since the magnets were measured as 11.88X 11.88X 11.88, these can be made as 12mm.

For this extrusion click once on each magnet slot, and the four pressure relief circles at each corner. When all selected for extrusion

After extrusion

Now extrude cut the holes.

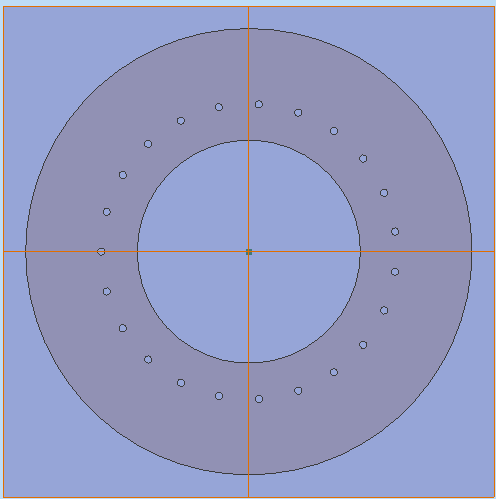
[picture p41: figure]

First, make the circles drawn for the hole extrusion visible.
Then, select extrude.
Later, draw the small circles for inserting the screws and lids.
After this action, draw the M4 circles where the brass rods will pass.

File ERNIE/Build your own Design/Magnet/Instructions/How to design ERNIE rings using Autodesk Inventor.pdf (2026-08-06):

## How to design ERNIE rings

### Step 1 – Install CAD Software

Install a CAD software package capable of creating and editing parametric 3D models. The ERNIE rings were designed using Autodesk Inventor Professional.

Students can obtain a free educational license from Autodesk:

https://www.autodesk.com/education/edu-software/overview#INVPROSA

Although Autodesk Inventor is used throughout this guide, the same design workflow can be implemented using SolidWorks, AutoCAD, or other equivalent CAD software.

Step 2 – Review the Ring Design Parameters

Before creating a ring model, review the optimization results to determine the dimensions and magnet configuration of the ring to be designed.
For example, Ring #288 has:
Inner bore diameter: 80 mm
Outer ring diameter: 160 mm
Outer shim tray diameter: 190 mm
Configuration_ Number | Band_ Number | Band_Radii_ Gap_mm | Magnet_ Space_mm | Band_ Separation_mm | Band_1_ Radius_mm | Band_1_ Magnet_Count
Ring_321 | 1 | 0 | 8.82 | 16.95 | 65.43 | 16
Ring_288 | 1 | 0 | 11.76 | 15.29 | 63.77 | 14
Ring_251 | 1 | 0 | 8.82 | 13.63 | 62.11 | 15
Ring_42 | 1 | 0 | 10.2941 | 3.6610 | 52.15 | 12

Total number of magnet used = ( Ring_321(16 magnets), Ring_288(14 magnets) 2, Ring_251(15 magnets)*2 and Ring_42( 12 magnets)*2). = 16+28+30+24 = 98 magnets.

Step 3 – Create a New CAD Part

Launch Autodesk Inventor and create a new metric part by selecting:

File → New → Templates → Metric → Standard (mm).ipt → Create

Using the metric template ensures that all dimensions are defined in millimetres.

For improved visibility, the workspace background may be changed by navigating to:

File → Options → Colors → Sky

Select Apply to save the changes.

Step 4 – Prepare the Sketching Workspace

When a new part is created, the reference planes are hidden by default. To make them visible, expand Origin in the Model Browser, right-click Planes, and select Visible. Repeat this for the YZ, XZ, and XY planes.

Next, right-click the XY plane and select Look At (or navigate to the Sketch tab and select the Perpendicular view) to orient the workspace normal to the sketch plane before beginning the design.

Step 5 – Create the Ring Geometry

Create a new sketch on the XY plane. From the Sketch tab, select Center Point Circle and draw three concentric circles, all originating from the center point.

- Set the inner bore diameter to 80 mm.

- Set the outer ring diameter to 160 mm.
- Draw a third concentric circle with a diameter of 190 mm to define the outer boundary for the shim trays.

These three circles establish the primary geometry of the ERNIE ring.

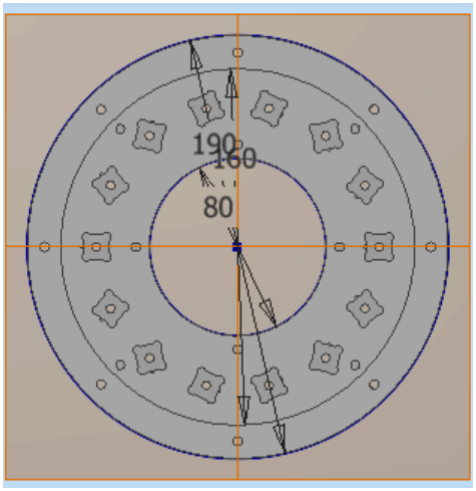
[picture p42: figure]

Step 6 – Extrude the Ring Geometry

After completing the sketch, select Finish Sketch to create the initial ring features.

First, select the inner circular region and apply an extrusion of 14 mm to create the inner section of the ring. After completing this extrusion, right-click the original sketch in the Model Browser and select Visible to display it again.

Next, select the outer circular region and apply an extrusion of 12 mm to create the remaining section of the ring.

The resulting geometry forms the stepped profile of the ERNIE ring, with a 14 mm inner section and a 12 mm outer section.

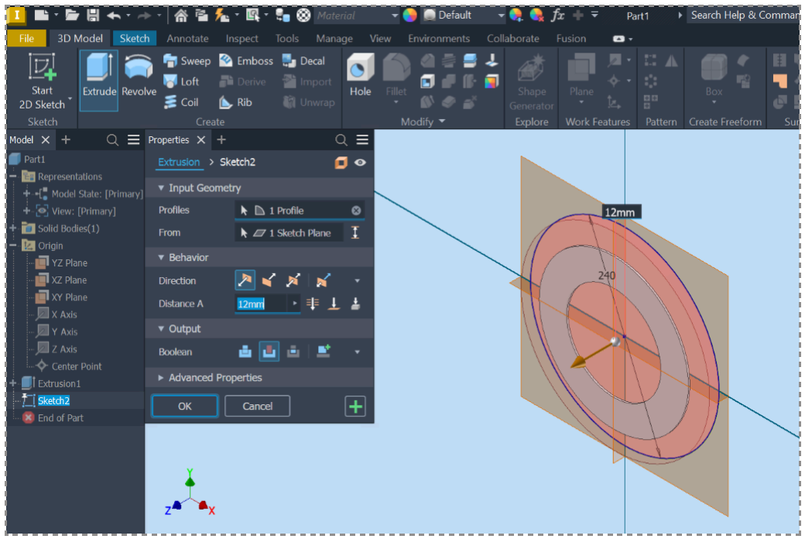
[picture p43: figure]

Step 7 – Create the Magnet Band Reference Circle

The magnet band dimensions are obtained from the optimized field results for each ring. For example, Ring #288 has a specified magnet band radius of 63.77mm.

Create a reference circle representing the magnet placement band by setting its diameter to:

2 × 63.773 mm = 127.546 mm

This reference circle defines the location where the magnet slots will be positioned within the ring.

Step 8 – Create the Magnet Block

Select Sketch 5, which contains the magnet band reference circle, and choose Edit Sketch to begin creating the magnet block.

Select the two side reference rectangles and draw a horizontal construction line passing through the center of the ring and intersecting the magnet band circle at 180°. This line establishes the reference position and orientation for placing the first magnet block.

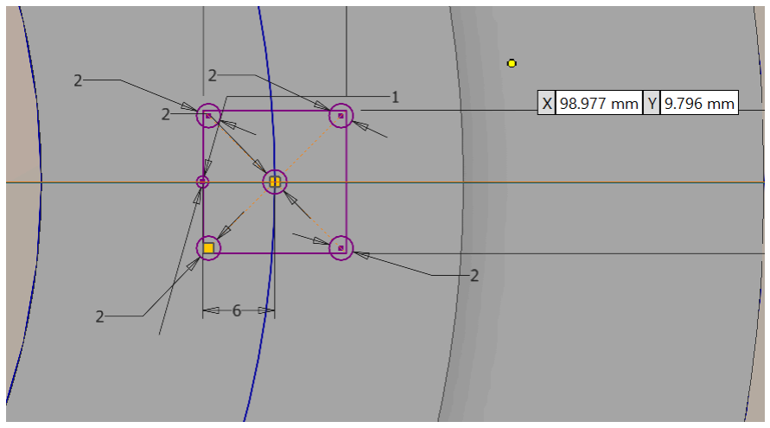
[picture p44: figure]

The dimensions of the neodymium magnets are measured as 11.8 mm × 11.8 mm × 11.8 mm. Therefore, dimension the magnet block as an 11.8 mm × 11.8 mm square to match the magnet dimensions.

Add a small reference point on the side of the square facing the center of the ring. This point defines the magnet rotation direction during placement within the Halbach array. Position the center of this reference point 6 mm from the center of the square and set its diameter to 1 mm.

Add four additional circles at the corners of the square. Set each corner circle diameter to 2 mm. These corner features provide clearance and allow the magnet to fit easily within the slot during assembly.

Add a circular opening at the center of the square and set its radius to 2 mm. This feature provides access for easier removal of the magnet from the slot if replacement or adjustment is required.

To convert the completed magnet slot geometry into a reusable block, navigate to:

Model Browser → Block → Create Block

Select all lines, circles, and reference points associated with the newly created magnet block.

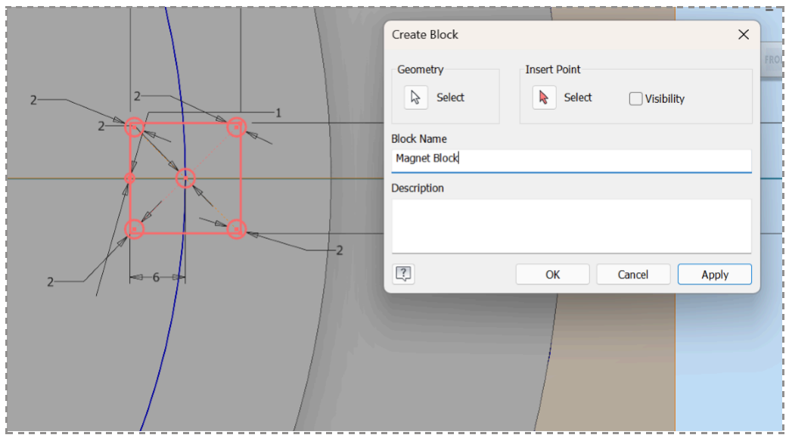
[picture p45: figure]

Select the Insert Point option and define the center of the magnet block as the insertion point. This establishes the reference location used when placing the magnet block around the magnet band.

Assign the block name “Magnet Block” and select Apply to create the block. After creation, the center points of the circles and rectangles within the block should change to white, indicating that the block has been successfully defined.

Select the green check mark to complete the block creation process.

To improve visibility, hide any unnecessary sketches and reference features, leaving only the magnet block visible. Finally, finish the sketch and hide it before proceeding to the next design step.

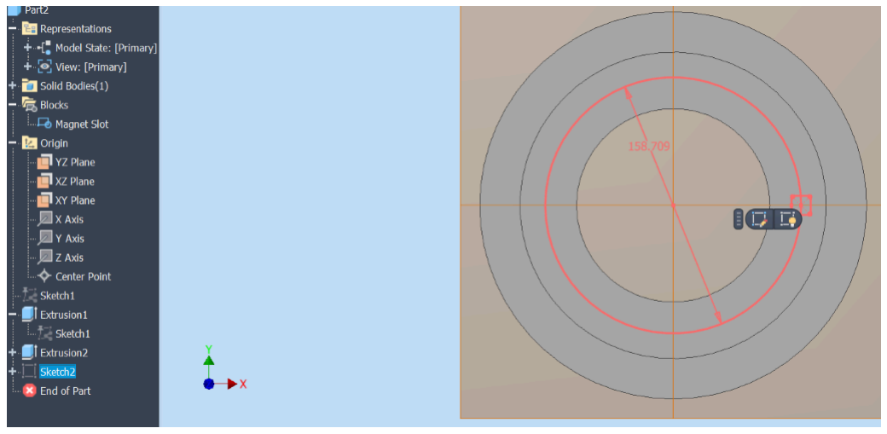
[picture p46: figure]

While remaining in Sketch Mode, create a new magnet band reference circle and set its diameter according to the design parameters. For Ring #288, the magnet band diameter is 127.546 mm.

Place a Magnet Block onto the reference circle. Initially, moving the block will cause the entire block to move freely. To constrain its rotation, draw a construction line from the center of the ring to the corresponding point on the magnet band circle. Position the magnet block at the intersection point between this line and the band circle. The center point of the magnet block should turn green, indicating that it is correctly constrained.

Verify the constraint by moving the magnet block. The block should rotate smoothly around the ring center through 360° while maintaining its position on the magnet band.

From the optimization results file, identify the required number of magnets for the selected ring. For example, Ring #288 requires 14 magnets.

To distribute the magnet blocks around the ring, use the Circular Pattern tool:

1. Select the horizontal construction line connecting the ring center to the magnet block center as the reference direction.
2. Select the center of the ring as the rotation axis.

3. Define the required number of pattern instances based on the magnet count.

For Ring #288, create a pattern of 7 magnet blocks. The remaining magnets are then placed by mirroring the arrangement to complete the ring configuration.

When placing each magnet block, ensure that the insert point (center point) turns green, confirming that the block is correctly positioned and constrained.

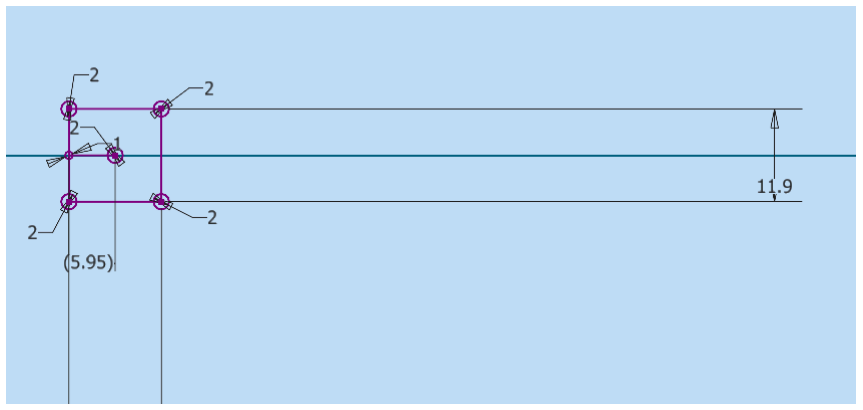
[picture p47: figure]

While still in Sketch Mode, select Edit Block to modify the magnet block geometry.

Draw a reference line connecting the center of the magnet block to the center of the small 1 mm diameter reference circle positioned 6 mm from the center of the magnet slot. This line defines the magnet orientation and serves as a reference for the rotation direction of the magnets within the Halbach array.

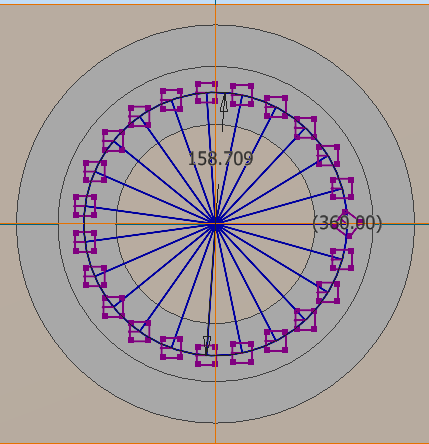
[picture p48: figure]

Step 9 – Define the Angular Orientation of Magnet Slots

Before applying angular dimensions to the magnet slots, slightly tilt the slots to prevent them from automatically constraining or snapping to existing geometry. This ensures that the applied dimensions are interpreted as angular constraints rather than linear measurements.

This step prepares the magnet slots for accurate definition of their rotational positions within the Halbach array.

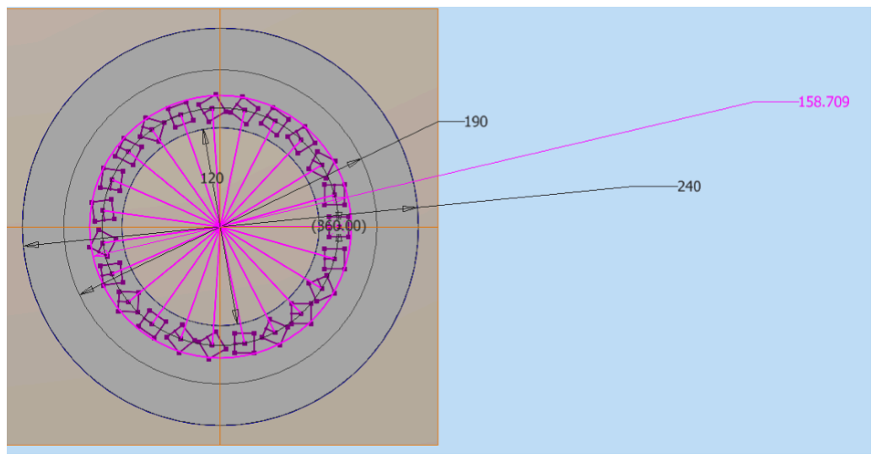
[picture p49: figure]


Step 10: Set Dimensions for the magnet slots.

To simplify the dimensioning process, ensure that all magnet slots are purple, indicating that they are flexible. This allows their dimensions and angular orientations to be modified. If the magnet slots appear blue, they are already fixed and cannot be adjusted.

The angular separation between the magnet slots is determined using the Halbach array formula:

360(2)/N

where N represents the number of magnets in the ring.

For example, for the 120 mm inner bore diameter rat scanner, the first ring designed was the middle ring (Ring #842). Based on the results obtained from the optimization algorithm, this ring contains 20 magnets.

The angular spacing is calculated as:

360(2)/20 = 36°

This means that there is an angular difference of 36° between each magnet slot.

Since the magnet slots are rotated in the counterclockwise direction, this value is entered as a negative angular dimension in the CAD software.

After applying the required angular dimension to a slot, its orientation becomes fixed. Fixed magnet slots appear blue, while flexible slots remain purple.

After applying all angular dimensions, all magnet slots should appear blue, indicating that they are fully constrained.

Next, navigate to:

Manage → Parameters

Review the listed angular parameters to verify that all magnet slot orientations have been correctly defined. If any incorrect values or errors are identified, make the necessary corrections before saving the final design.


Step 11: Modify the Magnet Block for Magnet Removal

Edit the Magnet Block and add a circular opening at the center of the block. This opening provides access for pushing the magnet out of the slot during removal or replacement, making the assembly and maintenance process easier.

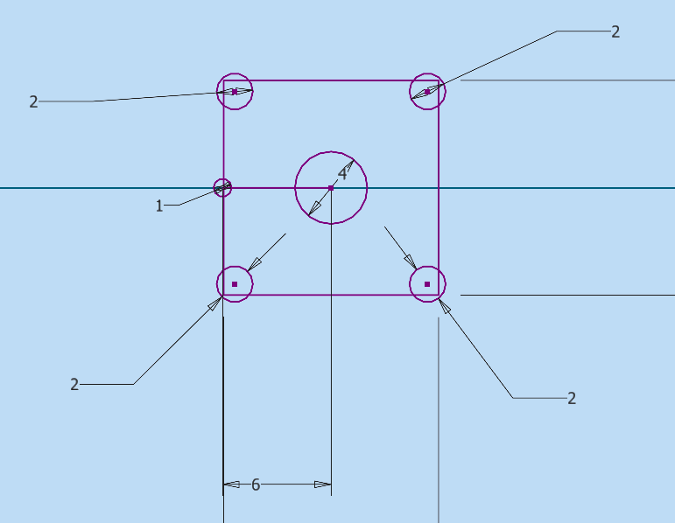
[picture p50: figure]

Step 12: Extrude the Magnet block

The measured dimensions of the neodymium magnets are 11.88 mm × 11.88 mm × 11.88 mm. For the CAD design, these dimensions are rounded to 12 mm to define the magnet slot depth and ensure sufficient clearance for magnet insertion.

Select the magnet slot regions and apply an extrusion of 12 mm to create the cavities where the magnets will be placed within the ring.

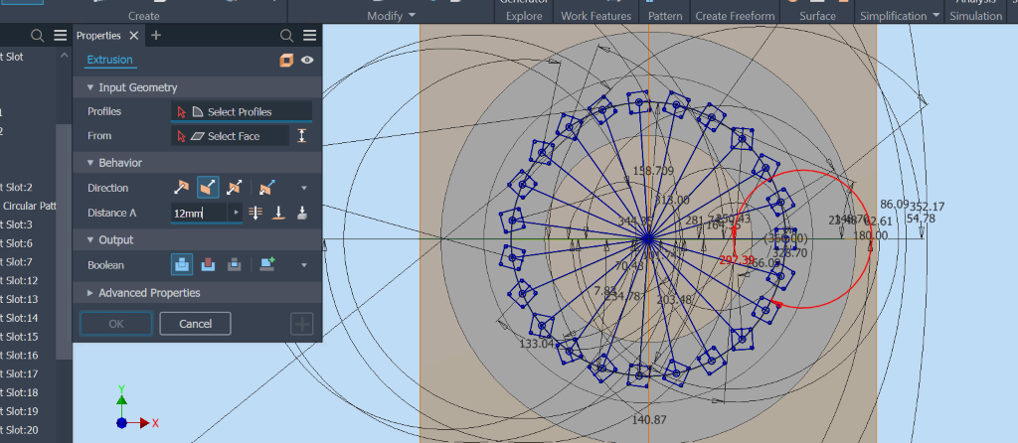
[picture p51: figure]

For this extrusion, select each magnet slot individually along with the four pressure relief circles located at the corners of each slot.

Once all required profiles are selected, proceed with the extrusion operation to create the magnet cavities and the associated clearance features.

After extrusion ( In Sketch Mode ) the ring looks like this one below:

Step 13: Extrude the 1.5 mm Diameter Holes

Next, create the small 1.5 mm diameter holes used as additional clearance features in the magnet slots.

Select Edit Sketch to access the hole profiles, then select all the 1.5 mm diameter circles. Apply an extrusion depth of 2 mm to create these features.

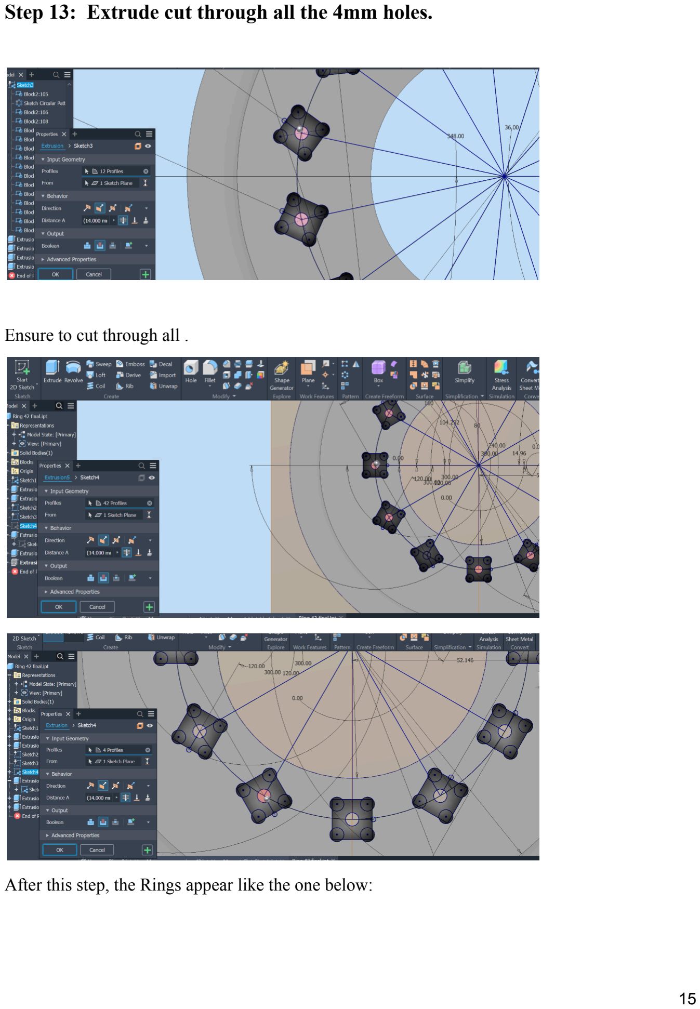
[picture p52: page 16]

Step 13: Extrude cut through all the 4mm holes.

Ensure to cut through all .

After this step, the Rings appear like the one below:

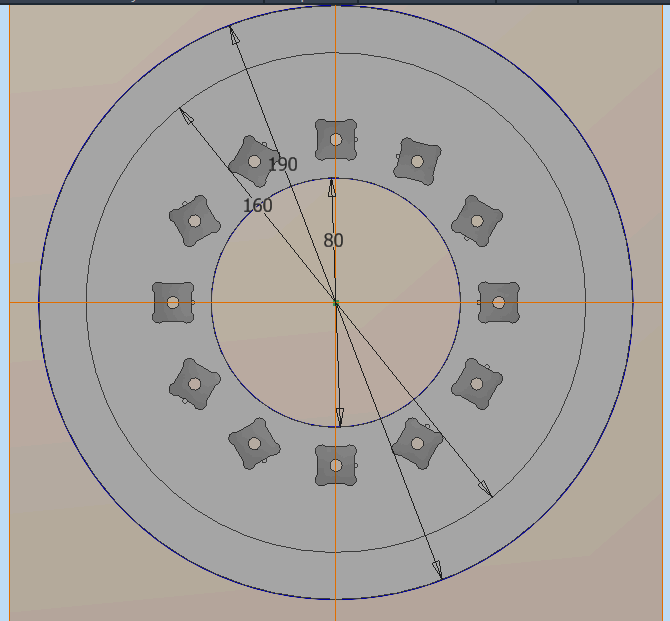
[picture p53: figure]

Step 14: Create Magnet Removal Holes and Mounting Features

The magnet slots are created with an extrusion depth of 12 mm to accommodate the neodymium magnets. The central hole used for magnet removal is created using an extrude cut through all, allowing access to push the magnet out of the slot when required.

The hole dimensions for the mounting features are defined as follows:

- M3 screw holes: 4.2 mm diameter
- M4 brass rod holes: 4.3 mm diameter

To create these features:

1. Make the previously drawn hole sketches visible.
2. Select the Extrude command and create the required hole features.

3. Create additional small circular sketches for the M3 screws used to secure the lids onto the rings.
4. Create the M4 circular holes through which the brass rods will pass.
5. Use Extrude Cut → Through All to create the holes through the entire ring thickness.

After completing these steps, the ring geometry should contain the magnet slots, magnet removal holes, lid mounting holes, and brass rod openings.

The figure below shows the final appearance of Ring #251 for the 50 mT small scanner before adding the remaining holes for the brass rods and lid fastening screws.

Front view

Back view

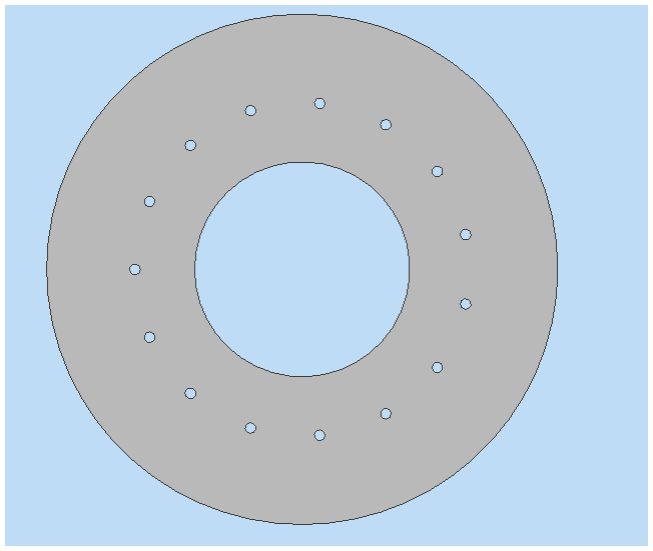
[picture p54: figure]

Step 15 – Create Brass Rod Holes

To create the holes for the brass rods:

1. Create a new sketch on the ring surface.
2. Draw a circle for the brass rod opening and set its diameter to 4.3 mm.
3. Dimension the circle immediately after creating it to ensure the correct size is maintained.
4. Use the Circular Pattern tool to replicate the hole around the ring, creating a total of 8 equally spaced holes.
5. Select Extrude Cut → Through All to create the brass rod holes through the entire ring.

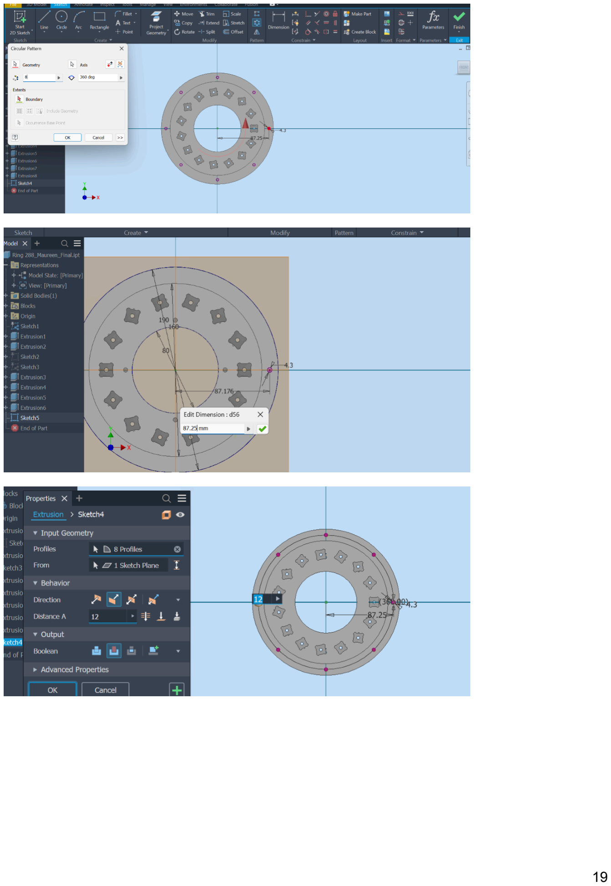
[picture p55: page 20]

Final result

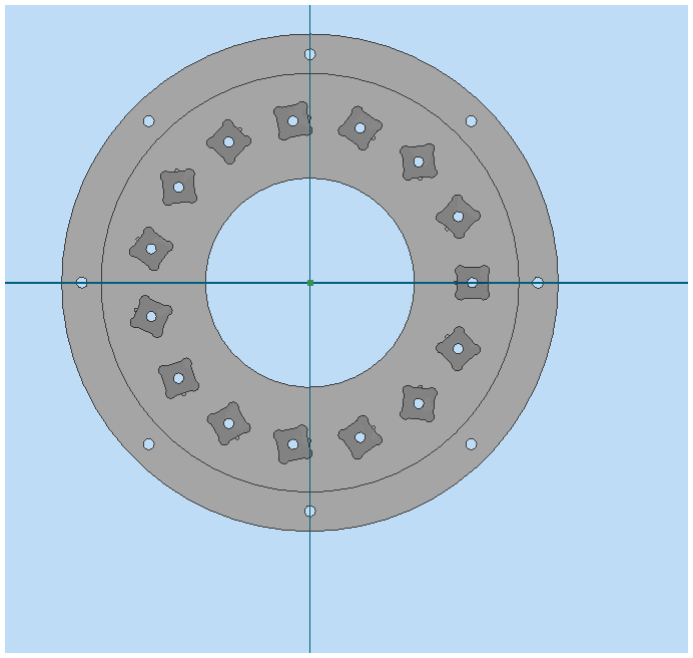
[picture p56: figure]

tep 16 – Create Heat-Set Insert and Lid Screw Holes

After creating the brass rod holes, add the holes required for installing the heat-set inserts and securing the lids.

1. Create a new sketch on the interior surface of the ring.
2. Draw the holes for the M3 screws and set their diameter to 4.2 mm.
3. Position the holes according to the ring design specifications.
4. Ensure that the holes do not overlap with the magnet slots, as this may affect the structural integrity of the ring.
5. Apply Extrude Cut → Through All to create the holes.

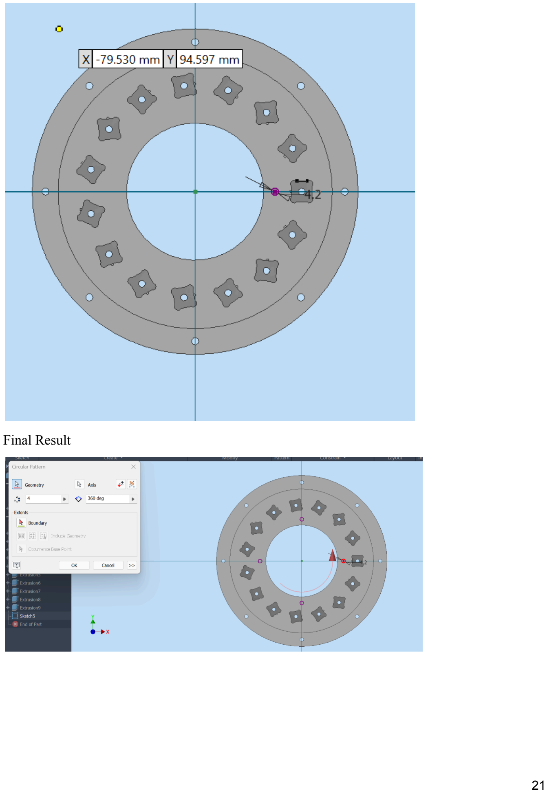
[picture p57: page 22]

Final Result

Step 17 – Create the Second Set of Inner Lid Screw Holes

For the second set of inner screw holes:

1. Draw a reference circle with a diameter of 150 mm.
2. Add M3 screw holes with a diameter of 4.2 mm.
3. Position the holes at 45° intervals around the ring.
4. Verify that the hole locations do not interfere with the magnet slots before creating the cuts.

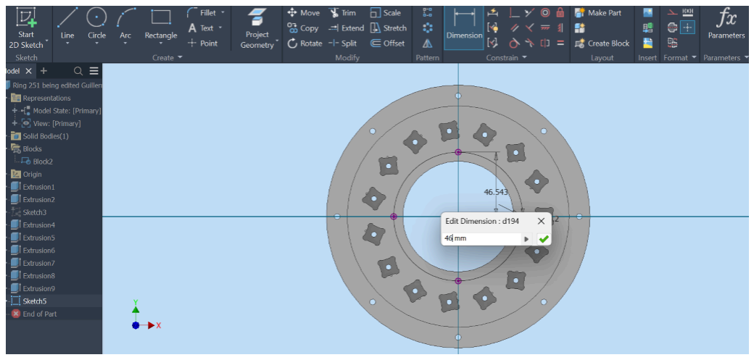
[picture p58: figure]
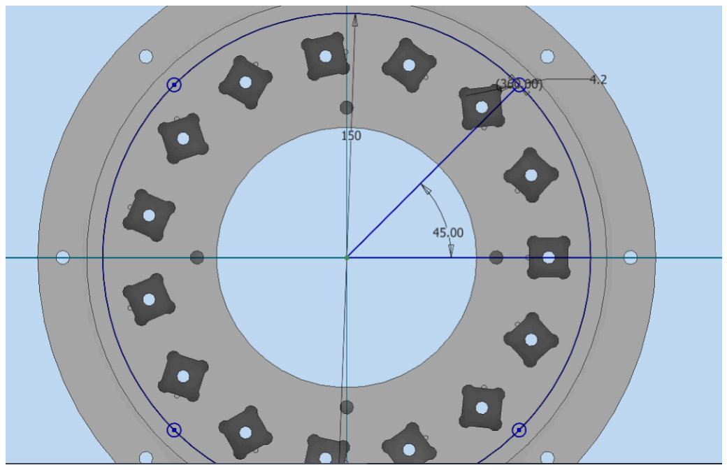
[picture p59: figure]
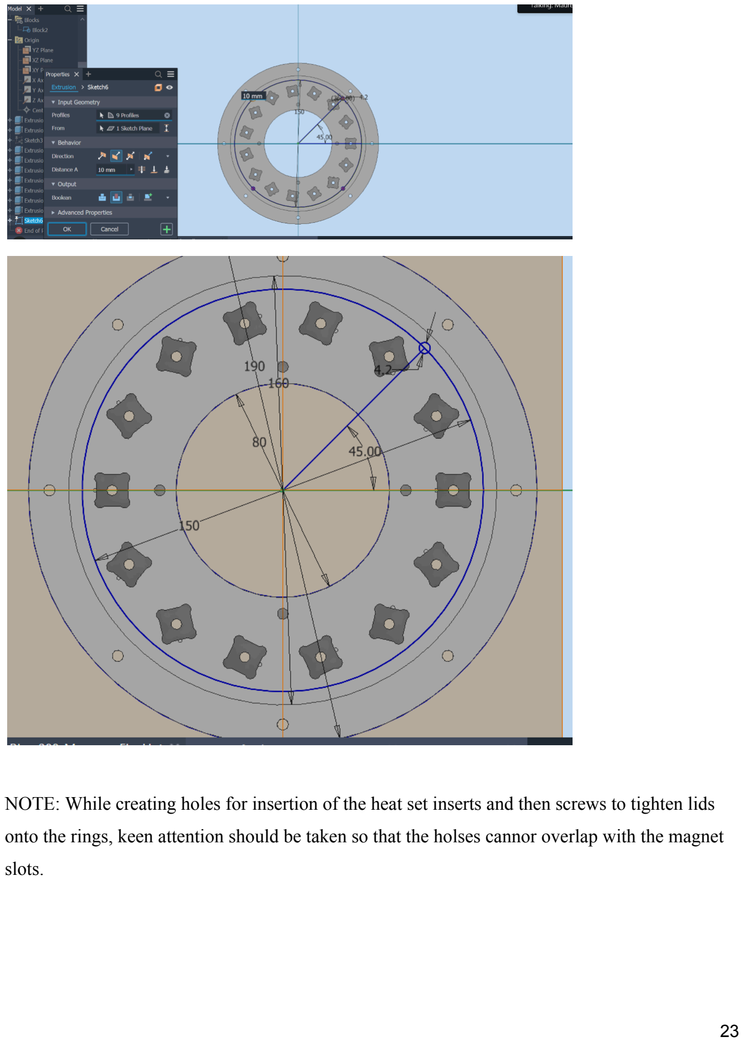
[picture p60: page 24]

NOTE: While creating holes for insertion of the heat set inserts and then screws to tighten lids onto the rings, keen attention should be taken so that the holses cannor overlap with the magnet slots.

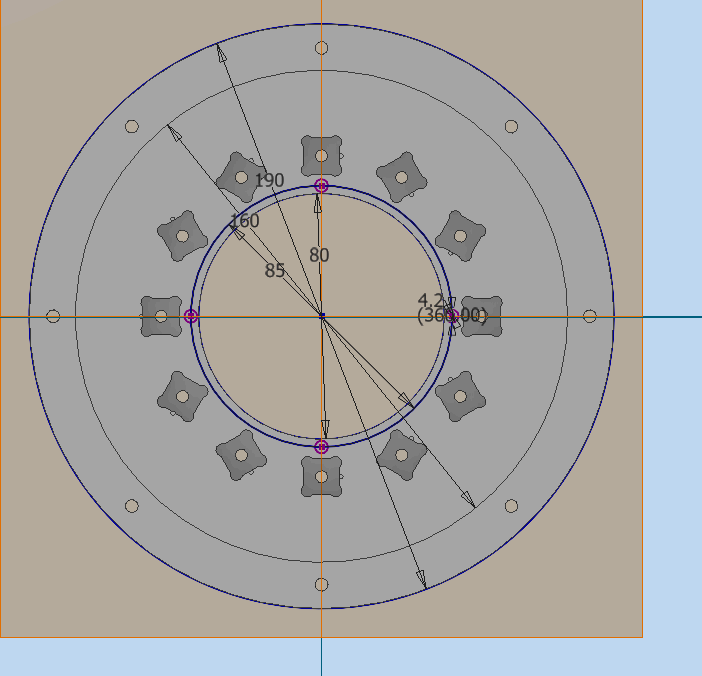
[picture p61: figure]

Step 18 – Ring #321 Design Considerations

Ring #321 requires a modified screw-hole arrangement because it is positioned further toward the exterior of the Halbach array.

For this ring:

- The reference circle immediately outside the magnet band is set to a diameter of 154 mm to provide sufficient space for lid fastening holes.
- The corresponding lid is designed using the same dimensions to ensure proper alignment and fit.

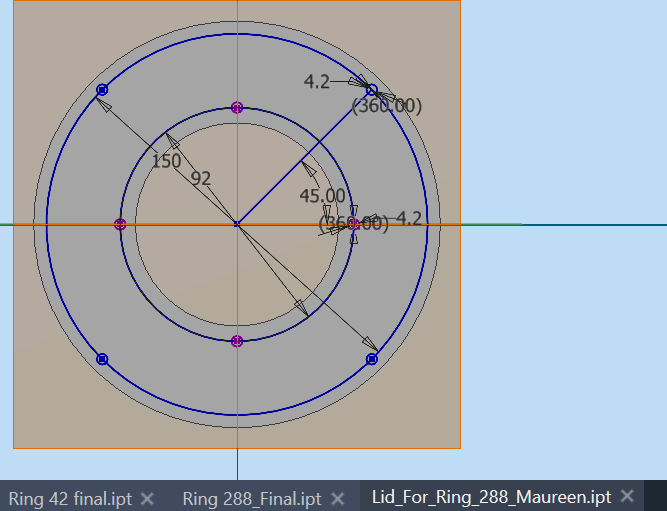
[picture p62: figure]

Step 19 – Design the Ring Supports for Ring #42 and Ring #321

The support structures for Ring #42 and Ring #321 are designed using the same approach. Since these rings are scaled versions of the 120 mm inner bore diameter rat brain scanner, the support dimensions are adjusted according to the corresponding ring geometry.

1. Create a new sketch on the ring surface.
2. Define the support geometry using the required dimensions based on the scanner design parameters.
3. Apply an extrusion of 12 mm to create the support structure.
4. Apply fillets to the edges of the support to improve the mechanical finish and reduce sharp edges.
5. Adjust and test different design parameters to achieve the desired support geometry and ensure proper fit.

The final support design should be verified after extrusion and filleting to confirm that it matches the intended ring configuration.

New sketch

Extrusion

Ring 321

Fillet the edges

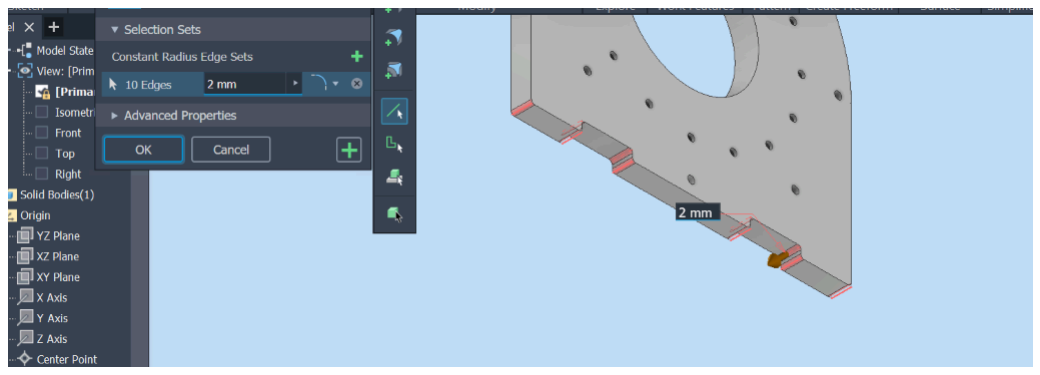
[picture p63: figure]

### Steps to design Lids

# Lid Design

Step 19 – Design Lids for Rings #288 and #251

The lids for Ring #288 and Ring #251 are designed using the corresponding ring dimensions.

1. Create a new sketch using the ring geometry as a reference.
2. Scale the lid features according to the requirements of the 120 mm inner bore diameter rat brain scanner.
3. Extrude the support structure to a thickness of 12 mm.
4. Apply fillets to smooth sharp edges and improve the final mechanical design.
5. Adjust design parameters as required and verify the final lid geometry.

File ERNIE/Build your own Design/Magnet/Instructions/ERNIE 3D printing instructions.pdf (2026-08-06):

ERNIE 3D printing instructions.

Requirements

Before printing the ERNIE components, ensure that the following requirements are met:

- A PLA-compatible 3D printer is required. The ERNIE components were printed using a Bambu Lab 3D printer. (https://ca.store.bambulab.com/collections/3d-printer?By+Series=P+Series) If using the same printer, it can be purchased from the manufacturer's website.
- Install Bambu Studio (https://bambulab.com/en-ca/download/studio) software, which is used to open, prepare, and generate print files from the provided .stl models.
- PLA filament is recommended for printing the ERNIE components.

## 3D Printing Procedure

Step 1: Install Bambu Studio Software

Download and install Bambu Studio (https://bambulab.com/en-ca/download/studio) before accessing the ERNIE 3D model files. The software is required to open, prepare, slice, and generate printing files from the provided .stl models.

Step 2: Download ERNIE 3D Model Files

Download the required ERNIE component files (https://github.com/CAMERA-MRI/IMAGINE/tree/main/ERNIE/Build%20your%20own%20Design/Magnet/Scanner%20parts%20for%203D%20printing) from the GitHub repository.

Step 3: Prepare the SD Card

Remove the SD card from the 3D printer and insert it into the computer. The generated printing files will be transferred to this SD card before loading them onto the printer.

Step 4: Open the STL File

Locate the required .stl (https://github.com/CAMERA-MRI/IMAGINE/tree/main/ERNIE/Build%20your%20own%20Design/Magnet/Scanner%20parts%20for%203D%20printing/ERNIE%201%262%20rings%20and%20l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) file and open it using Bambu Studio.

The model should appear as shown below:

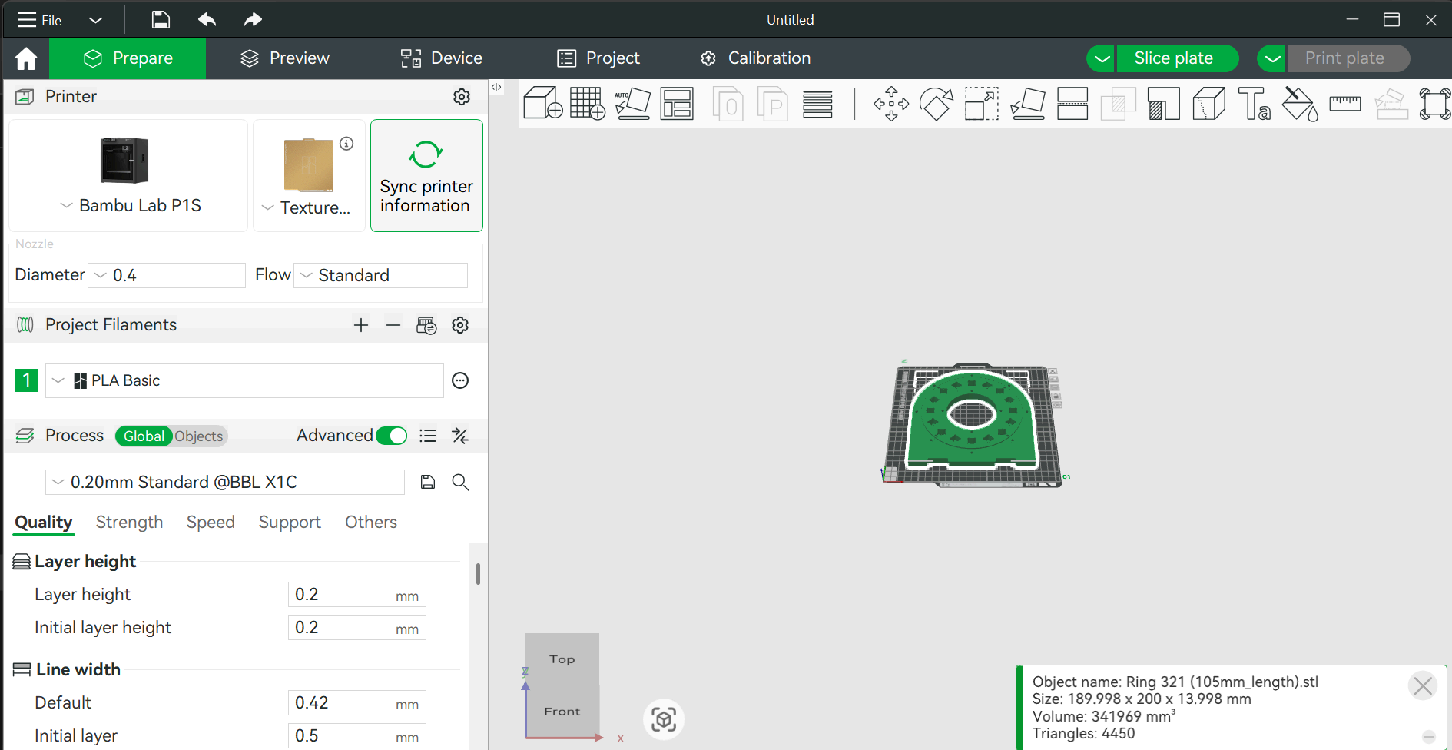
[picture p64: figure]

Step 5: Configure Printer and Material Settings

In the Global Settings panel on the left side of the Bambu Studio interface:

- Select the appropriate printer model from the printer drop-down menu.
- Select Bambu PLA Basic as the filament material.
- Select the printing process preset. The 0.20 mm Standard profile is recommended for general PLA printing.
Step 6: Configure Quality and Strength Settings

Navigate to the Quality tab and verify the layer height.

Under the Strength tab, use the following recommended settings:

- Infill density: 15–20%
- Infill pattern: Grid
- Supports: Not required for most ERNIE ring components.
Step 7: Slice and Preview the Model

Select Slice Plate in the upper-right corner of Bambu Studio.

Allow the software to generate the printing paths and layer information. Use the preview slider to inspect the model layer-by-layer.

Verify:

- Estimated printing time
- Filament usage
- Correct model preparation

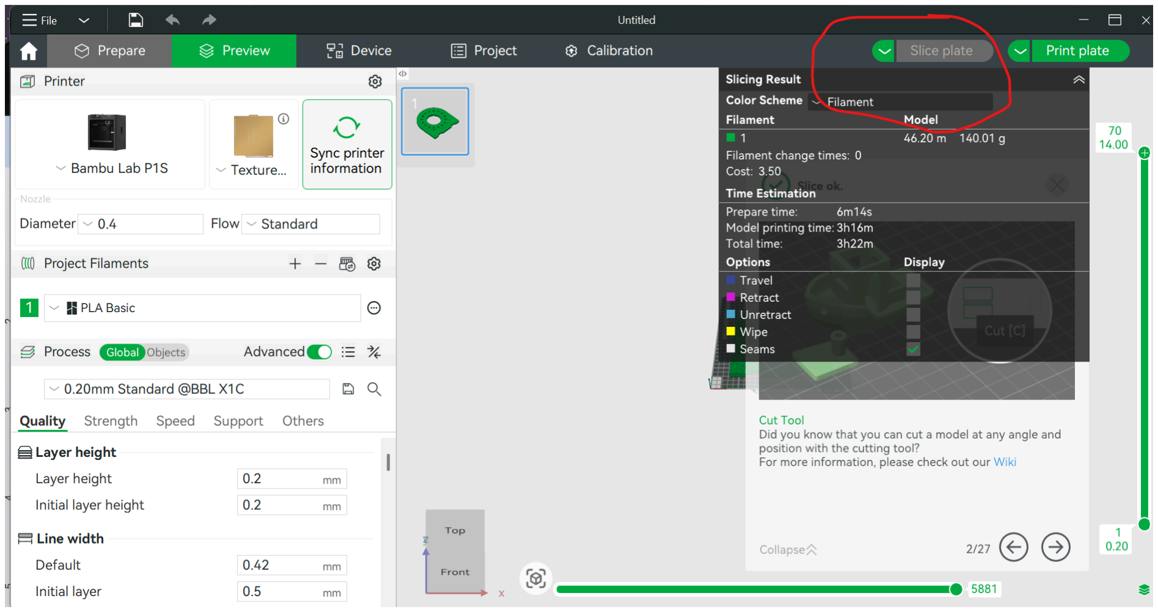
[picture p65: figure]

Step 8: Export the Printing File

From the top-left menu: File → Export → Export G-code

Save the generated file onto the SD card.

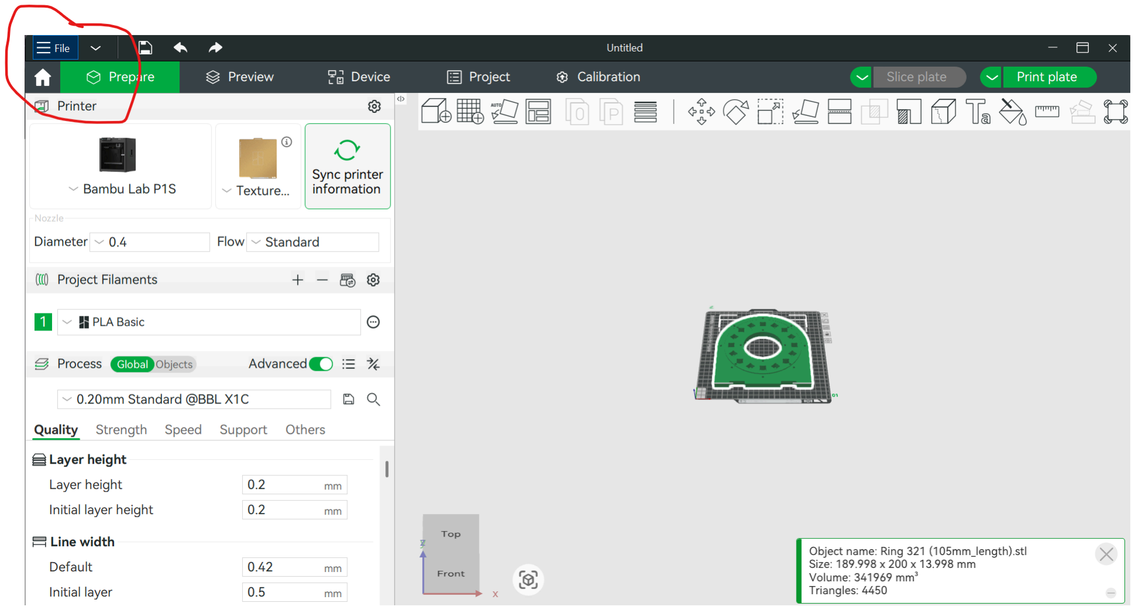
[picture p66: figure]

Step 9: Start Printing
- Load the printer with PLA filament.
- Turn on the 3D printer.
- Insert the SD card containing the G-code file.
- Select the desired ERNIE component.
- Confirm the selection to begin printing.
Step 10: Remove Printed Components

After printing is complete:

1. Allow the printer and component to cool for approximately 5 minutes.
2. Carefully remove the printed component from the build plate.
3. Repeat the process for all remaining ERNIE components.

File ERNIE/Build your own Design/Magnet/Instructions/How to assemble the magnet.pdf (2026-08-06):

## ERNIE Magnet Assembly Procedure

### Overview

The ERNIE toolkit provides a hands-on platform for learning the principles involved in constructing a low-field MRI system. The magnet assembly process involves preparing the mechanical components, installing magnets into the 3D-printed Halbach array rings, assembling the magnet structure, and verifying the resulting magnetic field configuration.

Before the start of the assembly session, few preparation steps are completed to ensure that the components are ready for assembly.

## 1. Pre-Assembly Preparation

### 1.1 Preparation of Brass Support Rods

The brass rods used to support and align the Halbach array structure are prepared before the assembly process.

A 1m brass rod is measured and cut into five sections, each with a length of 180 mm. These prepared rods are used during the final assembly stage to hold the magnet rings in alignment.

Figure 1: Brass rods cut to 180 mm length for Halbach array assembly.

### 1.2 Installation of Heat-Set Inserts

Due to restrictions on the use of soldering equipment in conference halls and workshop venues, the brass heat-set inserts are installed into the 3D-printed rings in a lab space, before the assembly sessions.

The inserts are installed by heating the soldering iron nozzle to the required temperature and carefully embedding each brass insert into its designated mounting hole. These inserts provide threaded attachment points for securing the ring lids.

During installation, controlled heat and gentle pressure are applied to ensure that each insert is:

- Properly aligned with the mounting hole
- Fully embedded within the printed material
- Flush with the ring surface

After installation, the rings are placed on a flat surface and allowed to cool completely before proceeding with magnet assembly.

Preparation of Ring Alignment Reference Marks

Before the assembly process, a horizontal reference line is marked on each 3D-printed ring to define the starting position for magnet placement. This reference line corresponds to the first magnet slot positioned at 0° relative to the horizontal axis of the ring. The marked reference position provides a consistent starting point for inserting magnets and ensures correct alignment and orientation of the magnets within each Halbach array ring. This is shown in Figure 2 below.


Figure 2: Ring #42 showing installed heat-set inserts and the 0° horizontal reference line for magnet alignment.

## Magnet assembly

Step 1: Arrange Components

All components are removed from the storage case and systematically arranged on a flat working surface.This allows participants to inspect the components, familiarize themselves with the assembly sequence, and prepare the workspace before beginning the build process.

Step 2: Arrange Neodymium Magnets

The neodymium magnets are removed from their storage boxes and arranged vertically in an organized manner. This arrangement facilitates efficient polarity identification and ensures that magnets can be handled safely during the assembly process.

Step 3: Identify the Reference Magnet Polarity

From the batch of neodymium magnets, four magnets are selected to be prepared as reference magnets for establishing the polarity orientation of the remaining magnets. One of the selected magnets is first used to determine its magnetic pole direction. A compass is used to identify the direction of the Earth's magnetic field and is then brought close to the selected magnet without allowing physical contact. The magnet face that attracts the north-seeking end of the compass is identified as the south pole, while the opposite face corresponds to the north pole. The north pole direction of the magnet is marked using a permanent marker, transforming it into a reference magnet. A small cardboard separator is attached to the opposite face using masking tape to provide physical separation and prevent unintended magnetic interactions during the polarity identification of the remaining magnets.

Step 4 – Polarity Identification and Marking of Remaining Magnets

A row of magnets is carefully brought into proximity with the reference magnet while maintaining controlled handling to prevent sudden magnetic attraction forces, which could cause the magnets to collide and potentially crack. This process is illustrated in Figure 3 below. The face of each magnet within the row that is attracted to the south pole of the reference magnet is identified as the north pole and marked accordingly. An arrow is drawn on each magnet to indicate the north pole direction. This procedure is repeated symmetrically for all remaining rows of magnets until the polarity of every magnet has been identified and clearly marked using permanent markers.

Figure 3: Row of magnets arranged for polarity identification and marking.

Step 5 – Placing Magnets into Ring Slots

Before installation, each neodymium magnet is inspected for visible defects, such as cracks or dents, that may affect its magnetic performance. The magnetic field strength of individual magnets can be verified using a Gauss meter by measuring the surface magnetic field, with N48 neodymium magnets expected to produce a field strength greater than 1 T near the magnet surface. The magnets are then inserted into their corresponding ring slots according to their marked polarities, starting from the slot positioned at 0° relative to the horizontal axis. During insertion, the arrow marking on each magnet is aligned with the circular indicator on the slot to ensure correct orientation. Figure 4 shows the magnet alignment in Ring #42.


Figure 4: Showing alignment of Neodymium magnets in Ring #42.

Step 6 – Verification of Magnet Orientation

After completing magnet placement in a ring, a second participant verifies that the magnets are inserted in the correct order and orientation. A compass is then used to confirm the Halbach array configuration (Figure 5). At the center of the ring, the compass should indicate a consistent magnetic field direction, while movement around the exterior of the ring causes the compass needle to rotate, confirming the expected internal and external field behavior of the Halbach array. This verification is repeated for all rings.


Figure 5: Verification of magnet orientation within the ring using a compass.

Step 7 – Securing Ring Lids

The corresponding lids are attached to each ring using M3 brass screws and screwdrivers. The brass screws are tightened securely to ensure that the magnets remain fixed within their slots during handling and subsequent assembly steps.


Figure 6: Rings containing magnets with lids securely attached.

Step 8 – Assembly of the Halbach Array

The Halbach array assembly begins by preparing the eight brass rods. A dome-shaped nut is first placed onto the end of each brass rod, and the rods are positioned vertically. Nylon washers are then added on top of the dome-shaped nuts to support the first ring.

The rings are assembled onto the brass rods in sequence. As each ring is placed, the lid side is kept facing upwards, and care is taken to ensure that the horizontal reference line marked on each ring remains aligned in the same direction throughout the assembly. This alignment maintains the correct relative orientation of the magnet rings within the Halbach array.

Ring #42 is first placed onto the eight brass rods. An individual ring spacer is then placed onto each of the eight brass rods above the ring before installing the next ring. The remaining rings and spacers are assembled in the following sequence:

Ring #42 → 8 Spacers → Ring #251 → 8 Spacers → Ring #288 → 8 Spacers → Ring #321 → 8 Spacers → Ring #288 → 8 Spacers → Ring #251 → 8 Spacers → Ring #42

After the final Ring #42 is installed, nylon washers are added onto the eight brass rods, and the assembly is secured using brass nuts tightened with spanners.

During the tightening process, a vernier caliper is used to measure the distance between adjacent rings and ensure that the spacing is maintained at 12 mm. If adjustments are required, the position of the rings is slightly modified while tightening the brass nuts until the correct spacing is achieved.


Figure 7: Halbach array ring assembly process and completed magnet assembly.


Supplementary Images
Visual assembly guides illustrating the scanner configuration and ring arrangement.

Pre-assembly arrangement of scanner components and required tools.

Assembled Scanner | Magnets in disassembly tray.

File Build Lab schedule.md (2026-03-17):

#                                                                                                                                                                                                                                                                                                                                                                                                                                                                                                                                                                                                                                                                                                                                                                                                                                                                                                                                                                                                                                                                                                                                                                                                                                                                                                                                                                                                                                                                                                                                                                                                                                                                                                                                                                                                                                                                                                                                                                                                                                                                                                                                                                                                                                                                                                                                                                                                                                                                                                                                                                                                                                                                                                                                                                                                                                                                                                                                                                                                                                                                                                                                                                                                                                                                                                                                                                                                                                                                                                                                                                                                                                                                                                                                                                                                                                                                                                                                                                                                                                                                                                                                                                                                                                                                                                                                                                                                                                                                                                                                                                                                                                                                                                                                                                                                                                                                                                                                                                                                                                                                                                                                                                                                                                                                                                                                                                                                                                                                                                                                                                                                                                                                                                                                                                                                                                                                                                                                                                                                                                                                                                                                                                                                                                                                                                                                                                                                                                                                                                                                                                                                                                                                                                                                                                                                                                                                                                                                                                                                                                                                                                                                                                                                                                                                                                                                                                                                                                                                                                                                                                                                                                                                                                                                                                                                                                                                                                                                                                                                                                                                                                                                                                                                                                                                                                                                                                                                                                                                                                                                                                                                                                                                                                                                                                                                                                                                                                                                                                                                                                                                                                                                                                                                                                                                                                                                                                                                                                                                                                                                                                                                                                                                                                                                                                                            Detailed Lab build schedule

### Main Magnet

| Day | Task | Status |
| :---- | :---- | :---- |
| 1 | Magnets \+ shimming magnets arrive |  |
| 1 | Parts arrive for B0 mapping |  |
| 1 | Internal shielding for RF: Copper sheet arrives |  |
| 1 | External shielding: Aluminium sheet arrives |  |
| 2 | Print shimming trays  |  |
| 2 | Cutting Rods |  |
| 2-3 | Magnets into Halbach array |  |
| 2-3 | Assemble Field Mapping Robot |  |
| 4 | Mapping the B0 |  |
| 5 | Shimming calculation |  |

### Control System

| Day | Task | Status |
| :---- | :---- | :---- |
| 0 | Order components for Red Pitaya to FHDO adapter |  |
| 1 | Aluminum MaRCoS box for Red Pitaya and FHDO arrives |  |
| 1 | Box for LNA and Switch arrives |  |
| 1 | Install MaRCoS and MARGE  |  |
| 5 | Mechanise MaRCoS box: power in for Red Pitaya, power for FHDO, 4 RF ports, ethernet, TTL output  |  |
| 5 | Mechanise LNA and Switch box: Power in port, RFPA in port, LNA out port, RF coil in and out port |  |

### RF

| Day | Task | Status |
| :---- | :---- | :---- |
| 0 | Order nanoVNA |  |
| 1 | Oscilloscope parts arrive |  |
| 1 | Order PCB / built PCB for Red PItaya to GPA-FHDO  |  |
| 1 | Set up Red Pitaya |  |
| 1 | Connectors for RF arrive |  |
| 1 | Print RF coil holder |  |
| 2 | Test connection between Red Pitaya and RFPA  |  |
| 2 | Check output of Red PItaya (MARGE vs Oscilloscope) |  |
| 2 | Check all components for TxRx switch |  |
| 3 | Set RF coil to Larmor Frequency 2.05 MHz |  |
| 3 | Make Switch for RF coil |  |
| 3 | Build Passive Switch |  |
| 3 | Build active Switch |  |
| 3 | Add variable capacitors to RF coils |  |
| 4 | RF holder for without gradients |  |

### Gradients

| Day | Task | Status |
| :---- | :---- | :---- |
| 0 | Order PCB / built PCB for Red PItaya to GPA-FHDO  |  |
| 0 | Order capacitors for filter |  |
| 1 | Gradient connectors arrive (Splice) |  |
| 1 | Power supply for FHDO arrives |  |
| 1 | Filter arrives |  |
| 1-2 | Print Gradient Holders |  |
| 3 | Winding Gradients |  |
| 4 | Filter circuit for FHDO |  |
| 7 | Testing Gradients |  |
| 7 | Gradient efficiency |  |

### Phantom and Acquisitions

| Day | Task | Status |
| :---- | :---- | :---- |
| 2 | CN Tower phantom design |  |
| 2 | Print rat phantom |  |
| 4 | CN Tower printing |  |
| 4 | Rat phantom solutions |  |
| 5 | CN Tower filling |  |
| 5 | Fill rat phantom |  |

[image1]: <>

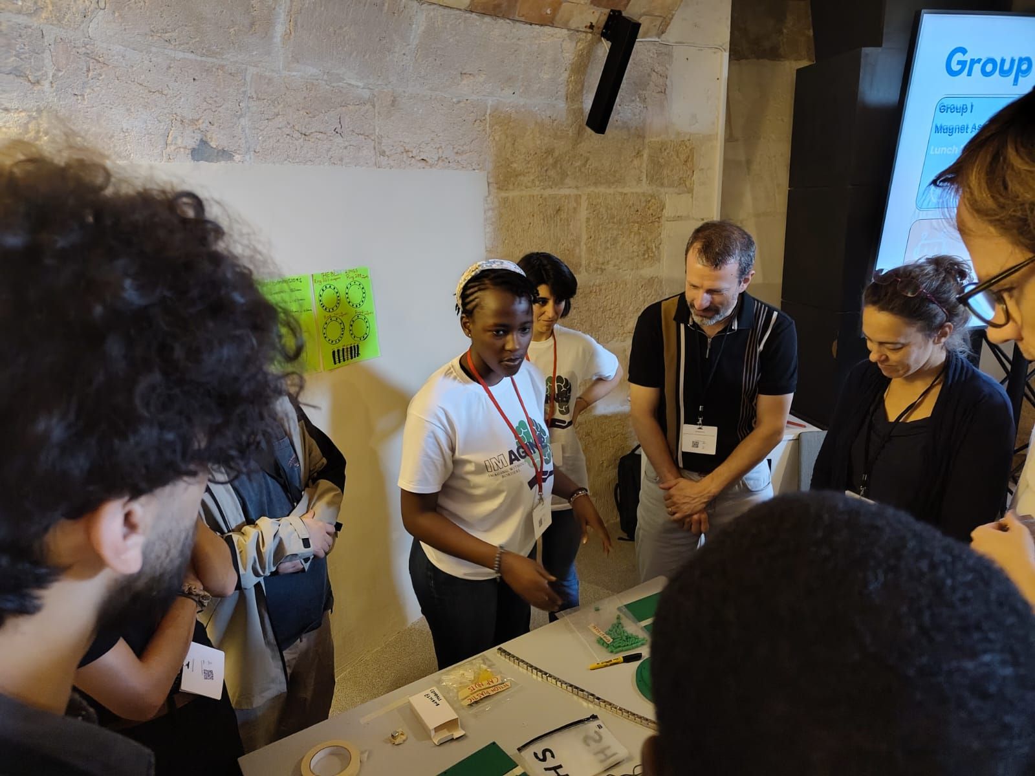
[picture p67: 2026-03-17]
images/Magnet assembly team ESMRMB.jpeg

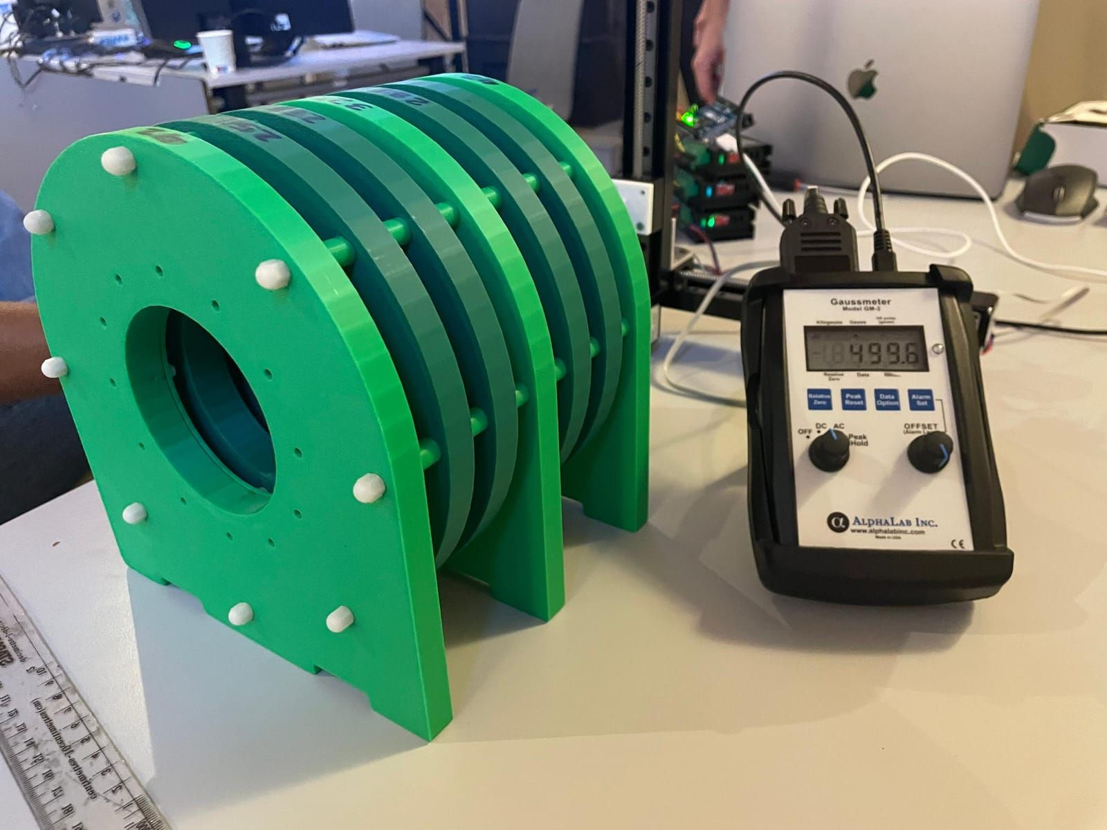
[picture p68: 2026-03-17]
images/Assembled magnet at ESMRMB.jpeg

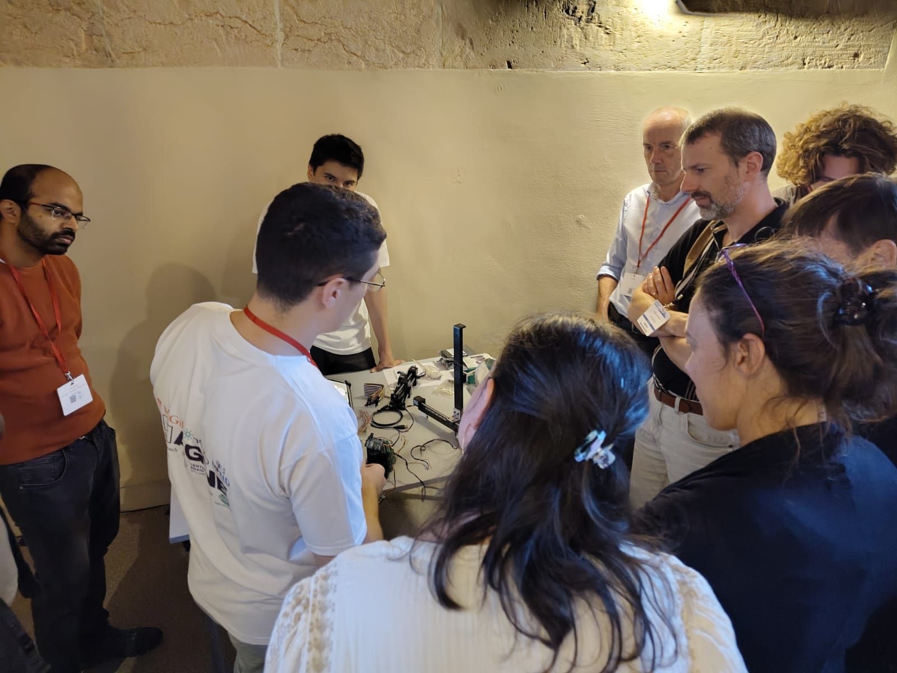
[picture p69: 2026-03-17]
images/Robot assembly team ESMRMB.jpeg

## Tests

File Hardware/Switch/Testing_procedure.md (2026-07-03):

**To test the RF Switch**

Using a VNA calibrated to the magnets working frequency, go through the following combinations in reflection and transmit mode. All components not being tested at a given moment need to be connected to a 50 Ohm load. 

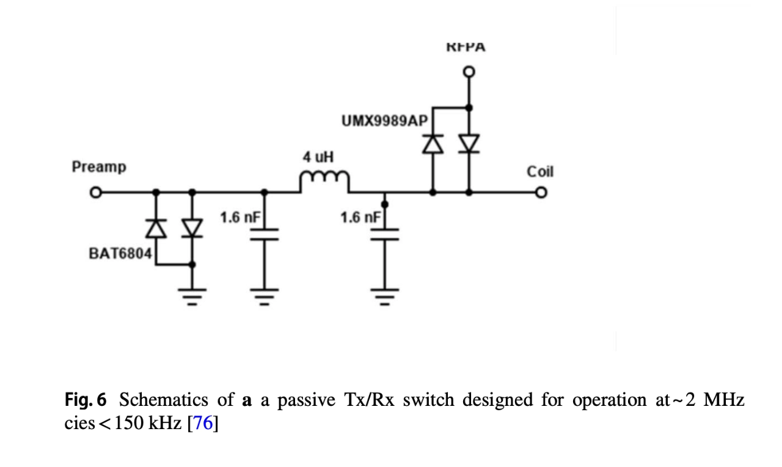
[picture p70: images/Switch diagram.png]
Switch.
<br/><br/>

| **Reflection (S11/S22 on VNA)** | Signal Source | E.g. Working active switch | Your switch |
| --- | --- | --- | --- |
| Transmit mode (Switch ON) | Tx | -23 |  |
| Transmit mode (Switch ON) | Coil | -21.2 |  |
| Receive mode (Switch OFF) | Coil | -22.9 |  |
| Receive mode (Switch OFF) | Rx | -22.4 |  |
| **Transmission (S12/S21 on VNA)** | **T - R** |  |  |
| Transmit mode (Switch ON) | Tx - Coil | -0.24 |  |
| Transmit mode (Switch ON) | Tx - Rx | -39.5 |  |
| Transmit mode (Switch ON) | Coil - Rx | -40.4 |  |
| Receive mode (Switch OFF) | Tx - Coil | -53.4 |  |
| Receive mode (Switch OFF) | Tx - Rx | -50 |  |
| Receive mode (Switch OFF) | Coil - Rx | -0.21 |  |

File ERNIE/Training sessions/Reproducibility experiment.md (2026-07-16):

**Reproducibility experiment**
<p style="text-align: justify;">
To evaluate the reproducibility of the ERNIE toolkit, we conducted multi-site reconstruction experiments in which independent teams rebuilt the scanner at geographically distinct locations using similar documentation and design package, including training package, instructions and kit. The primary objective was to assess whether the toolkit enables consistent system reconstruction and functional performance regardless of change in site.
</p> 

<p style="text-align: justify;">
  Reproducibility was assessed across 3 different dimensions: (i) Assembly reproducibility, (ii) operational reproducibility and (iii) consistency in field map results. 
</p> 

<p style="text-align: justify;">

**Outcome**
 
All participating sites successfully reconstructed the scanner and robot using the same ERNIE kit. These sites included ESMRMB (ERNIE 1), The Neuro (ERNIE 2), Polytechnique Montreal(ERNIE 2), Montreal General Hospital (ERNIE 2), The Douglas (ERNIE 2) and ISMRM (ERNIE1 & ERNIE2). 
</p>

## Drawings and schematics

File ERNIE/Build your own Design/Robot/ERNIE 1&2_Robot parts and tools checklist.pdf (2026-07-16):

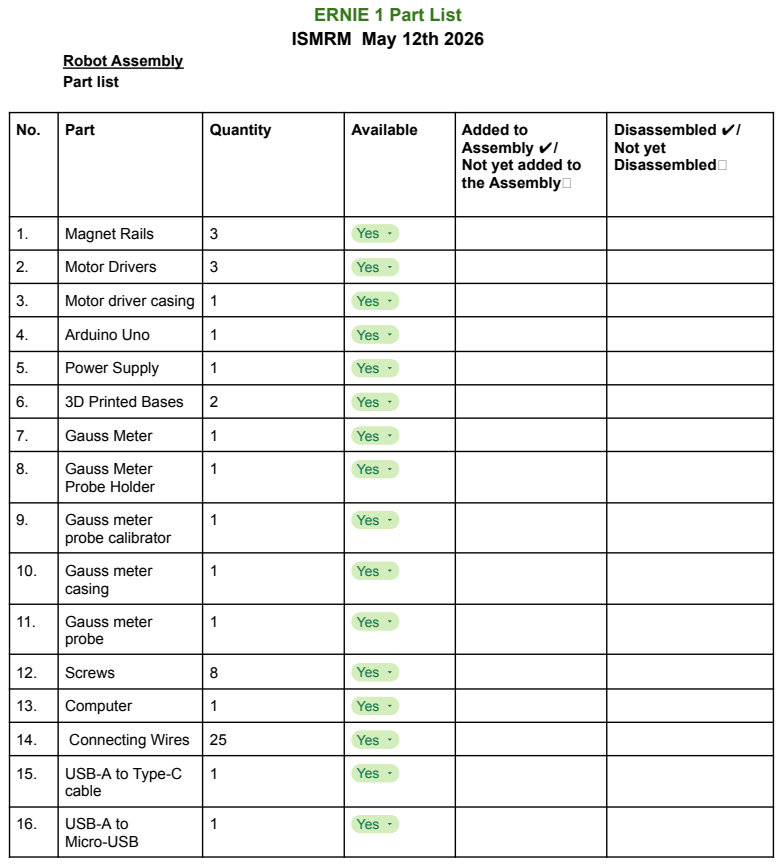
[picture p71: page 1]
Robot Assembly Part list

ERNIE 1 Part List
ISMRM May 12th 2026

No. | Part | Quantity | Available | Added to Assembly ✔/ Not yet added to the Assembly | Disassembled ✔/ Not yet Disassembled

1. | Magnet Rails | 3 | Yes

2. | Motor Drivers | 3 | Yes

3. | Motor driver casing | 1 | Yes

4. | Arduino Uno | 1 | Yes

5. | Power Supply | 1 | Yes

6. | 3D Printed Bases | 2 | Yes

7. | Gauss Meter | 1 | Yes

8. Gauss Meter | Probe Holder | 1 | Yes

9. Gauss meter | probe calibrator | 1 | Yes

10. Gauss meter | casing | 1 | Yes

11. Gauss meter | probe | 1 | Yes

12. | Screws | 8 | Yes

13. | Computer | 1 | Yes

14. | Connecting Wires | 25 | Yes

15. USB-A to Type-C | cable | 1 | Yes

16. USB-A to | Micro-USB | 1 | Yes

Tools needed for Magnet Assembly

No. | Tool | Quantity | Available | Returned to box ✔/ Not returned to the box
1. | Screw Drivers | 4 | Yes
2. | Tape | 2 | Yes
3. | Ruler | 2 | Yes
4. | Allen keys | 2 | Yes
5. | Pliers | 1 | Yes

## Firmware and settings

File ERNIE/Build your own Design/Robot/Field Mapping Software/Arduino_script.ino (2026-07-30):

/* ──────────── pin map (unchanged) ──────────── */
const int Step_z = 7, Dir_z = 6;
const int Step_x = 5, Dir_x = 4;
const int Step_y = 3, Dir_y = 2;

#define STEPS_PER_MM  1600   // 1-mm move = 533 pulses,(533.33333334) now the modified calibration will be 1066.666667, new value 1600
#define PULSE_US      200            // HIGH / LOW time per pulse

void setup() {
  Serial.begin(9600);                // must match the Python BAUD
  pinMode(Step_z, OUTPUT);  pinMode(Dir_z, OUTPUT);
  pinMode(Step_x, OUTPUT);  pinMode(Dir_x, OUTPUT);
  pinMode(Step_y, OUTPUT);  pinMode(Dir_y, OUTPUT);
}

/* ───────── main loop: parse newline-terminated commands ───── */
void loop() {
  static char line[16];
  static byte idx = 0;

  while (Serial.available()) {
    char c = Serial.read();

    if (c == '\n' || c == '\r') {     // end of command
      line[idx] = '\0';
      idx = 0;
      handleCmd(line);
    } else if (idx < sizeof(line) - 1) {
      line[idx++] = c;               // build token
    }
  }
}

/* ───────── command dispatcher ───────── */
void handleCmd(const char *cmd) {
  if      (!strcmp(cmd, "X+")) { digitalWrite(Dir_x, HIGH); moveSteps(Step_x); }
  else if (!strcmp(cmd, "X-")) { digitalWrite(Dir_x, LOW);  moveSteps(Step_x); }
  else if (!strcmp(cmd, "Y+")) { digitalWrite(Dir_y, LOW);  moveSteps(Step_y); } // Reversed direction
  else if (!strcmp(cmd, "Y-")) { digitalWrite(Dir_y, HIGH); moveSteps(Step_y); } // Reversed direction
  else if (!strcmp(cmd, "Z+")) { digitalWrite(Dir_z, HIGH); moveSteps(Step_z); }
  else if (!strcmp(cmd, "Z-")) { digitalWrite(Dir_z, LOW);  moveSteps(Step_z); }
  /* any other string is ignored */
}

/* ───────── 1-mm step routine ───────── */
void moveSteps(int stepPin) {
  for (int i = 0; i < STEPS_PER_MM; ++i) {
    digitalWrite(stepPin, HIGH);
    delayMicroseconds(PULSE_US);
    digitalWrite(stepPin, LOW);
    delayMicroseconds(PULSE_US);
  }
}

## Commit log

2026-03-17 RF coil and halbach array
    [Brass_Rod_M4.ipt, Lid_Loose.ipt, Lid_tight.ipt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]
2026-03-17 OSOH, structure, checklist
    [Brass_Rod_M4.ipt, Lid_Loose.ipt, Lid_tight.ipt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]
2026-03-17 Create CAD files
    Gradient Coils CAD files
2026-03-18 Create CAD files
2026-03-18 Update CAD files
2026-03-23 Halbach magnet description
    [Brass_Rod_M4.ipt, Lid_Loose.ipt, Lid_tight.ipt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]
2026-03-23 Rename 1759942020484.jpeg to Scanner assembly team ESMRMB.jpeg
2026-03-23 Rename 1759942020542.jpeg to Robot assembly team ESMRMB.jpeg
2026-03-23 Rename 1759942020552.jpeg to Assembled magnet at ESMRMB.jpeg
2026-03-23 Rename 1759942020644.jpeg to Magnet assembly team ESMRMB.jpeg
2026-03-23 Rename 1759943810642.jpeg to Magnet team ESMRMB.jpeg
2026-06-29 Add STL files for scanner parts
    [Lid_For_Ring_321.stl, Lid_For_Ring_42.stl, Lid_For_Rings 288 and 251.stl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]
2026-06-29 Move ERNIE ring and lid STL files into dedicated folder
    [Lid_For_Ring_321.stl, Lid_For_Ring_42.stl, Lid_For_Rings 288 and 251.stl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]
2026-07-03 Rename Screenshot 2026-07-03 at 17.40.36.png to Switch diagram.png
2026-07-03 Rename Switch diagram to Switch diagram.png
2026-09-10 Rename CAD files to CAD
